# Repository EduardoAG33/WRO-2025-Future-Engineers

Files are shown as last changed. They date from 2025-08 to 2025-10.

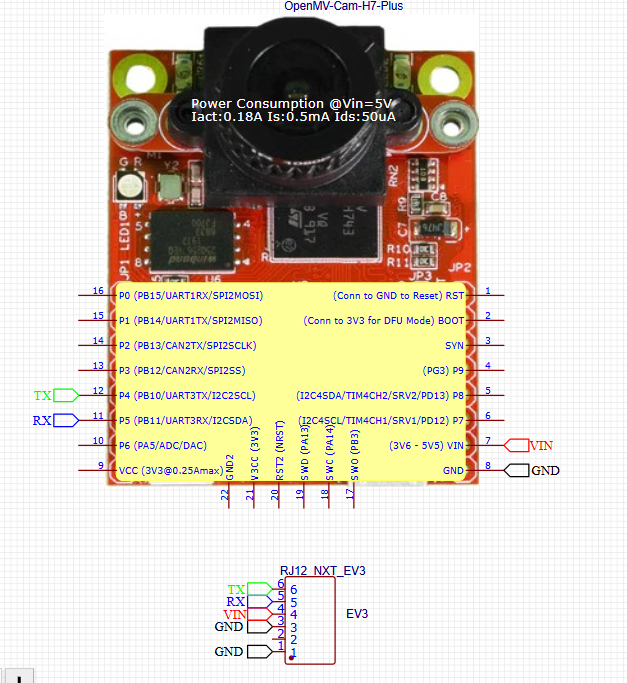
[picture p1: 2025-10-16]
Schemes/open mv schematic.png

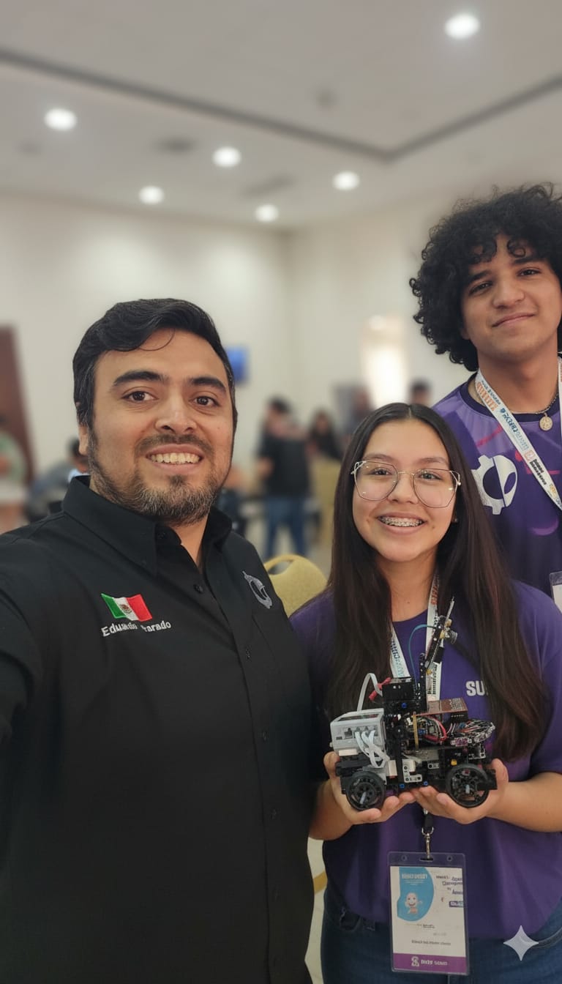
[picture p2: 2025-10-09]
Team-Photos/Team photo.jpeg

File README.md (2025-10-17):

# 🤖 WRO-2025-Future-Engineers

Official repository of Team Los Grises Superiores for the **Future Engineers – World Robot Olympiad 2025**.  
<div align="center">
team-image
</div>

---

## 📸 Team photo
<div align="center">
  team-photo
</div>

---

## 👥 Team Members

### Eduardo Alvarado Gonzalez
<div align="center">
Eduardo Gonzalez
</div>

**Role:** Coach and founder

An engineer and professor founded the **Los Grises Superiores** in 2014, since then with outstanding national and international participations.

---

### Eric Daniel Guerrero Uresti
**Age:** 22
<div align="center">
  Eric Guerrero photo
</div>

**Role:** Programming & Mechanics

I started participating in robotics tournaments from 2016 to 2019, achieving **two second places** in the Mexican Robotics Tournament (TMR). Due to the **Covid-19 pandemic**, I couldn’t compete again until 2024, when I returned as a **coach** in TMR and WRO, earning a spot at the international competition. I am currently in my final year of **Mechatronics Engineering**.

---

### Paulina Ibarra Martínez
**Age:** 20
<div align="center">
  Paulina Martinez photo
</div>

**Role:** Programming & Electronics

I have been part of the **Robotics Club** at *Escuela Normal Superior “Profr. Moisés Sáenz Garza”* for three years, participating in **two Mexican Robotics Tournaments**, achieving **5th place** in the most recent one. Starting in 2024, I became a **junior coach**, achieving **third place** in WRO 2024 and **first place nationally** in the Mexican Robotics Tournament 2025.

---

## 📚 Contents
- [Project Overview](#project-overview)
- [Vehicle Photos](#vehicle-photos)
- [Components and Hardware](#components-and-hardware)
- [Mobility Management](#mobility-management)
  - [Chassis](#chassis)
  - [Steering System](#steering-system)
  - [Movement and Traction System](#movement-and-traction-system)
  - [Differential](#about-differential)
- [Power and Sense Management](#power-and-sense-management)
  - [Power Management](#power-management)
  - [Sense Management](#sense-management)
- [Obstacle Management](#obstacle-management)
  - [Vision System](#vision-system)
- [Calibration](#calibration)
- [Detection and Avoidance Strategies](#detection-and-avoidance-strategies)
- [WRO 2025 Competition Info](#wro-2025-competition-info)

---

## Project Overview

### Abstract

We present the **development and implementation of an autonomous vehicle** designed for the **World Robot Olympiad 2025 – Future Engineers** category.  
The competition challenges participants to design, construct, and program a self-driving car capable of completing specific tasks under variable environmental and rule-based conditions.

The **Future Engineers** category consists of **two main challenges**:

1. **Open Challenge**  
   - The vehicle must autonomously complete **three laps** on a predefined track.  
   - The **starting position** and **driving direction** (clockwise or counterclockwise) are **randomly assigned** before each run.

2. **Obstacle Challenge**  
   - Similar to the Open Challenge, but the vehicle must **detect and react to colored pillars** acting as traffic signals:  
     - **Red pillars → Turn right**  
     - **Green pillars → Turn left**

**Documentation:**  
Documentation is a critical component of the challenge, as it reflects the team’s **engineering process**. Teams are required to maintain a **public repository** including code, CAD files, logs, and other technical documentation.

For full rules and official specifications:  
🔗 [WRO 2025 Future Engineers – General Rules (PDF)](https://wro-association.org/wp-content/uploads/WRO-2025-Future-Engineers-Self-Driving-Cars-General-Rules.pdf)

---

## Vehicle Photos

<div align="center">

| Front | Back |
|:--:|:--:|
 |  |

| Bottom | Top |
|:--:|:--:|
| Top | Bottom |

| Left | Right |
|:--:|:--:|
| Left | Right |

</div>

---

## 🎥 Project Videos

<div align="center">

### 🧩 Open Challenge  


---

### 🚧 Obstacle Challenge  


</div>

---

---
## Components and Hardware

| Component | Description | Image | Purchase Link |
|---|---|---|---|
| **45544 LEGO MINDSTORMS Education EV3 Core Set** | Forms the foundational structure and chassis. | <div align="center">EV3 Core Set</div> | [Buy here](https://bricks-store.com/esp/item/585/66/45544-set-base-lego-mindstorms-education-ev3) |
| **OpenMV Cam H7 Plus** | Smart camera for navigation and obstacle detection. | <div align="center">OpenMV Cam H7 Plus</div> | [Buy here](https://openmv.io/products/openmv-cam-h7-plus) |
| **HC-SR04 Ultrasonic Sensor** | Distance measurement sensor. | <div align="center">HC-SR04</div> | [Buy here](https://uelectronics.com/producto/sensor-ultrasonico-hc-sr04/) |
| **DFRobot URM09 Ultrasonic Sensor (Gravity Analog)** | This ultrasonic sensor features an open dual-probe design and uses the standard Gravity PH2.0-3P vertical connector. Compatible with controllers operating at 3.3V or 5V logic levels. | <div align="center">DFRobot Ultrasonic Sensor</div> | [Buy here](https://wiki.dfrobot.com/URM09_Ultrasonic_Sensor_(Gravity_Analog)_SKU_SEN0307) |
| **Arduino Nano** | ATmega328-based microcontroller for control tasks. | <div align="center">Arduino Nano</div> | [Buy here](https://www.steren.com.mx/placa-de-desarrollo-nano.html) |
| **4x4 RGB LED Matrix** | Compact display module consisting of 16 individual LEDs arranged in a 4-row by 4-column grid. | <div align="center">4x4 RGB Matrix</div> | [Buy here](https://mvelectronica.com/producto/matriz-de-led-rgb-4x4-ws2812-16bits-a-5v-led-5050) |
| **Mini 560 Step-Down Regulator** | Converts a higher voltage power source to a lower voltage efficiently. | <div align="center">Mini 560</div> | [Buy here](https://uelectronics.com/producto/mini-560-regulador-step-down/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) |
| **DFRobot Gravity BNO055** | Intelligent 9-axis Absolute Orientation Sensor integrating a triaxial accelerometer, gyroscope, geomagnetic sensor, and a 32-bit microcontroller. | <div align="center">BNO055</div> | [Buy here](https://es.aliexpress.com/i/32950220044.html?gatewayAdapt=glo2esp) |
| **Digital Voltmeter** | Measures the electrical potential difference between two points in a circuit. Ideal for monitoring battery voltage and ensuring stable power supply. | <div align="center">Voltmeter</div> | [Buy here](https://www.amazon.com.mx/Volt%C3%ADmetro-pulgadas-volt%C3%ADmetro-protecci%C3%B3n-amarillo/dp/B07P1RV5B1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) |
## Mobility Management

### Chassis
The main chassis consists of LEGO pieces selected for their accessibility and for enabling a compact and efficient design. Initially, the prototype was designed using Studio 2.0 software to ensure proper part selection and structural balance.  
For the second level, an acrylic base (acrylate polymer) was used to support the ultrasonic sensors. The shape of this base was customized as part of the design by applying heat to specific areas to mold it into the desired form.  
This level integrates five ultrasonic sensors, strategically distributed to enhance environmental detection and obstacle avoidance.  
This design was made in OnShape:

<div align="center">
Ultrasonic and PCB Base
</div>

The elaboration process:

Using a heat gun, each side of the acrylic base designated for the sensors was carefully heated. Once the material reached the appropriate temperature, it was bent using a mold to achieve the 90° angle required for the optimal positioning and field of view of the sensors.

<div align="center">
Acrylic bending     
Molded base
</div>

The final result is mounted on the robot:

<div align="center">
Mounted base
</div>

This base is attached to the chassis using four screws in the middle to give it stability, and on top of this locate the PCB is located where the ultrasonic sensors are connected.

The measurements for the sensor support can be found in the datasheet.

<div align="center">
sensor support
</div>

## DATASHEET:

https://github.com/EduardoAG33/WRO-2025-Future-Engineers/blob/main/Others/HC-SR04_Datasheet_with_Dimensions%20(1).pdf

**base 3**

On the PCB board, we mounted an additional acrylic base to secure the camera, and to place a voltmeter and a switch for the 18650 batteries. The gyroscope sensor is located in the central part of the assembly for optimal orientation measurement.

<div align="center">
PCB acrylic base
</div>

**view in the vehicle**

<div align="center">
view in the vehicle
</div>

And for the upper level of the robot, we have the support for the camera and the Neo pixel light:  

<div align="center">
camera support
</div>

The support is positioned at a 70° inclination to ensure the vehicle remains within the maximum allowed height. This angle was carefully chosen to optimize the camera’s field of view, as detailed in the Power and Sense Management section.

**Changes and improvements**

Initially, the robot used two cameras. The first camera detected walls, while the second read floor lines for lap counting and identified pillar colors in the Obstacle Challenge. This setup aimed to avoid extra sensors due to the cameras’ high precision.

However, issues arose with ambient light sensitivity, calibration time, and battery consumption. To improve reliability, the second camera was replaced with five ultrasonic sensors positioned at frontal, 90°, and 45° angles to measure distances to walls.

The sensors communicate with the EV3 via two Arduino Nanos: one collects the data, and the other sends it via I2C. The system is mounted on a custom PCB.

**Before:**



**Now**



## Base for the VL53L0X

**Solidworks software design**(metric system in mm)

<div align="center">
VL53 base design
</div>

**draw measurements**

<div align="center">
draw measurements
</div>

This custom piece is designed to fit perfectly with LEGO components, allowing it to be mounted on the chassis and securely hold the sensor according to the dimensions specified in its datasheet.

The custom piece and sensor are precisely positioned to ensure optimal alignment and secure integration with the LEGO chassis, based on the sensor’s datasheet dimensions.

<div align="center">
custom piece
</div>

## Problems and solutions
**Change of the sensor** 

we decided to change the previous sensor (VL53L0X) since when doing tests we had performance failures based on the walls since the distances varied a lot because the sensor laser is affected by the black color of the walls. We determined this by changing to a white color and seeing that the distances no longer varied with this, at the time of having the error this causing it to collide with the stops.
Solution:
The change was implemented for an ultrasonic DF robot URM09, it is working better, the objective changed it was no longer necessary to use it for parking, but as an aid to the turn sensor at the end of the laps of the open challenge round in case the vehicle finished outside the section, this ultrasonic would mark the distance (or the one in front depending on the height at which the robot finishes) to join the final arrival area.
To place the sensor, it only fits on the base of the previous one.
<div align="center">


---

**Chassis render**
<div align="center">
chassis render
</div>

**Assembly manual:**
[chassis assambly instruction.pdf](https://github.com/user-attachments/files/22890187/chassis.assambly.instruction.pdf)

**material that makes up the structure of the chassis:**
<div align="center">
material 1
</div>

<div align="center">
material 2
</div>

<div align="center">
material 3
</div>

In the Mexican National Tournament, we only used one differential, and the robot dimensions were both wider and taller. For the updated version, we decided to implement two differentials, as this configuration provides significantly better control when moving forward. Additionally, reducing the robot’s overall dimensions helps prevent collisions with obstacles and makes it easier to maneuver around them.

---

### Steering System
The EV3’s middle motor converts rotational motion into steering movement through a gear train mechanism. The wheels are linked by a connecting rod, allowing them to move freely. With the assistance of the front differential, this setup transmits motion through the drivetrain to the rear motors, enabling smooth and controlled movement.

The steering rotation is limited to 45 degrees due to the chassis design; however, this range is sufficient for proper turning and obstacle avoidance. If needed, the rotation angle can be further reduced through the block programming.  
**Functionality:**

- **Pinion (engranaje circular):** The circular gear located at the center of the structure. When it rotates, it moves the rack from side to side.  
- **Rack (toothed bar):** A long bar with teeth that meshes with the pinion. When the pinion turns, the rack slides horizontally.  
- **Wheel connection:** The ends of the rack are linked to the wheels through steering arms. When the rack moves, it pushes or pulls these arms, causing the wheels to turn.

<div align="center">
  steering system
  <p><em>Steering system render</em></p>
</div>

**material that makes up the structure of the steering:**
<div align="center">
 steering material
</div>
  
**Assembly manual**
[Sterring system manual.pdf](https://github.com/user-attachments/files/22892572/Sterring.system.manual.pdf)

---

### Movement and Traction System
Two medium motors with differential system transmit energy to wheels. Transmission: 20-tooth → 12-tooth gears → 28-tooth → 20-tooth driving wheels. Position accuracy ±1°, torque 0.08 Nm, speed 240 RPM.  
According to the competition rules, the engines cannot be mounted directly on the wheels. Therefore, we chose to implement a transmission system connected to the differential, allowing the engine’s motion to be transferred to the tires, causing them to rotate.  
We decided to use two motors because they offer greater speed, power, and stability to the vehicle’s base compared to using only one. This configuration allows for a more balanced distribution of torque, improving traction and control during movement. After testing different options, we chose the medium LEGO motor because it provides an optimal balance between size, weight, and energy efficiency, making it ideal for our chassis design. Additionally, its compact structure facilitates integration into the transmission system while maintaining low power consumption and reliable performance.

<div align="center">
traction system
</div>

**Traction system render**

<div align="center">
 traction render
</div>

**Traction system manual**
[traction system manual.pdf](https://github.com/user-attachments/files/22892680/traction.system.manual.pdf)

---

### About Differential
Distributes torque to wheels, enabling smooth cornering. Input via pinion and crown gears. Outer wheel rotates faster in turns, inner wheel slower, straight motion equal.

A differential is a mechanical component that allows wheels on the same axle to rotate at different speeds while transmitting power from the motor. This is especially important when a vehicle turns, as the outer wheel needs to travel a greater distance than the inner wheel. The differential distributes torque between the wheels, ensuring smooth and efficient movement, reducing tire wear, and improving traction and stability. In our design, the differential receives motion from the transmission and transfers it to the tires, enabling precise control of the vehicle’s movement.

<div align="center">
  Differential example
  <p><em>Image: Differential example</em></p>
</div>

**LEGO Differential Calculations – Gear Ratio Table**

| Gear Ratio (i) | Wheel Speed (m/s) | Wheel Torque (N·m) | Traction Force (N) |
|---|---|---|---|
| 1:1 | 0.50 | 0.20 | 7.14 |
| 2:1 | 0.25 | 0.40 | 14.3 |
| 3:1 | 0.17 | 0.60 | 21.4 |
| 4:1 | 0.13 | 0.80 | 28.6 |
| 5:1 | 0.10 | 1.00 | 35.7 |

- Assumes **motor speed = 170 rpm**, **torque = 0.2 N·m**, **wheel radius = 0.028 m**.

## Impact of vehicle dimensions

The robot’s compact dimensions — 15 cm wide, 29 cm long, and 26 cm high — allow for the precise integration of both the steering and traction systems, enabling accurate and stable turns.
It was designed to be as narrow as possible, minimizing the risk of collisions with walls during sharp turns.

In the Open Challenge, our robot uses five ultrasonic sensors together with an OpenMV camera, creating an intelligent system that allows it to detect obstacles and move safely.
The front ultrasonic sensor detects when a curve begins. The camera and ultrasonic sensors work together through a PID control system, and we also correct measurement errors from the ultrasonic sensors using gain adjustments depending on their inclination.
This helps the robot identify whether a corridor is open or closed, effectively avoiding collisions with walls and improving navigation accuracy.

For the Obstacle Challenge, we took advantage of the robot’s width, length, and height to optimize its performance in different scenarios.
The width, being narrow, allows the vehicle to pass easily between pillars without collisions.
The length was optimized for the parking task — we extended the vehicle and added a rear spoiler to make the most of the rule that define the parking area as 1.5 times the vehicle’s length. This provides more freedom and precision when parking.
The height was designed to ensure better visibility of obstacles, allowing the sensors and camera to detect objects from their base to their top. This also prevents the robot from re-detecting the same obstacle after an evasive maneuver or a sharp turn, ensuring smoother navigation and preventing unnecessary repeated avoidance actions.

---

## Power and Sense Management
The Power and Sensor Management system of the vehicle is engineered to optimize energy distribution and ensure reliable operation of all electronic components. It carefully regulates the power supply to motors and sensors, maintaining stability and efficiency under varying load conditions. This system enables precise control over sensor readings and motor performance, supporting accurate navigation, obstacle detection, and overall vehicle functionality.
   
### Battery for EV3:
<div align="center">
EV3 Battery
</div>

**Specifications:**

| Specification | Details |
|---|---|
| **Battery Type** | Rechargeable Lithium-Ion (Li-Ion) |
| **Nominal Voltage** | 7.4 V (Li-Ion) |
| **Capacity** | 2000 mAh (Li-Ion) |
| **Typical Usage Time**  | Approximately 1–2 hours with intensive use of motors and sensors |
| **Charging Time** | 1.5 – 2 hours (Li-Ion) |
| **Weight** | 160 g (Li-Ion) |
| **Connector** | Integrated in EV3 Brick |
| **Note** | Using the official rechargeable Li-Ion battery is recommended for optimal performance and to avoid voltage variation from AA batteries |

This battery is the recommended power source for the LEGO EV3. There are two options: the official rechargeable battery or six AA batteries. Using the official battery is preferable, as it provides a stable and consistent voltage, ensuring reliable operation of motors and sensors under varying loads. Additionally, it offers longer runtime, making it ideal for extended use and competitive.

### Battery 18650
<div align="center">
18650 battery
</div>

**Specifications:**

| Specification | Description |
|---|---|
| **Type** | Li-ion Rechargeable |
| **Model** | 18650 |
| **Nominal Voltage** | 3.7 V |
| **Full Charge Voltage** | 4.2 V |
| **Capacity** | 2600–3500 mAh (typical) |
| **Discharge Current** | 5–10 A (continuous), up to 20 A (peak) |
| **Charging Current** | 0.5–1 C |
| **Dimensions** | 18 mm diameter × 65 mm length |
| **Weight** | ~45 g |
| **Cycle Life** | 300–500 cycles (typical) |
| **Protection Circuit**  | Optional (PCB for overcharge/discharge/cutoff)|

The 18650 is Li-ion battery is a high-capacity rechargeable cell widely used in electronics and robotics due to its stable voltage output, high energy density, and long cycle life.
can safely deliver continuous currents of 5–10 A and occasional peak currents up to 20 A,When paired with a protection circuit, it safeguards against overcharging, over-discharging, and short circuits, increasing safety and durability.
In this setup, we use 18650 batteries to power the Arduino Nano for controlling the ultrasonic sensors. Two 18650 cells are connected to a DC-DC step-up module to increase the voltage, which is then supplied to the Arduino, ensuring stable operation and consistent sensor readings, we We use two 18650 batteries connected in series, providing an output voltage of approximately 7V.

### Microcontroller(Arduino nano)
<div align="center">
Arduino Nano large
</div>

**Specifications:**

| Specification | Description |
|---|---|
| **Microcontroller** | ATmega328P |
| **Operating Voltage** | 5 V |
| **Input Voltage (recommended)** | 7–12 V |
| **Input Voltage (limit)** | 6–20 V |
| **Digital I/O Pins** | 14 (6 PWM outputs) |
| **Analog Input Pins** | 8 |
| **DC Current per I/O Pin** | 40 mA |
| **Flash Memory** | 32 KB (2 KB used by bootloader) |
| **SRAM** | 2 KB |
| **EEPROM** | 1 KB |
| **Clock Speed** | 16 MHz |
| **USB Connection** | Mini USB |
| **Dimensions** | 45 mm x 18 mm |
| **Weight** | ~7 g |

The Arduino Nano is a compact,microcontroller board based on the ATmega328P. Despite its small size, it offers full functionality with 14 digital I/O pins, 8 analog inputs, and a 16 MHz clock speed.
It operates at 5V and can be powered through a Mini USB connection, a regulated 5V pin, or an external 7–12V input,

### Medium motor EV3
<div align="center">
EV3 Medium Motor
</div>

**Specifications**

| Specification | Description |
|---|---|
| **Model** | EV3 Medium Motor (45503) |
| **Type** | Servo Motor with integrated rotation sensor |
| **Operating Voltage** | 9 V DC |
| **Nominal Power** | 2.5 W |
| **No-load Speed** | ~260 rpm |
| **Stall Torque** | ~8 N·cm (0.08 N·m) |
| **Stall Current** | ~0.7 A |
| **Tacho Sensor Resolution** | 1° (360 counts per rotation) |
| **Weight** | 75 g |
| **Cable Length** | 25 cm |
| **Connector Type** | EV3 Plug |
| **Control Features** | Speed, position, and direction control |

It operates at 9V DC and is designed to provide a balance between speed and torque, making it suitable for medium-load
We connect these motors directly to the EV3, and control them directly with the programming block for these motors, which in our robot consumes the following:

EV3 Brick controls all motors. Powered by 10V 2050 mAh battery.  
- **Movement motors (2):** 150–250 mA  
- **Steering motor (1):** 120–250 mA
  
In terms of power consumption, the motor typically draws around 250–300 mA under normal load, but this can increase up to 1.2 A when operating under heavy load or stall conditions. Its power output reaches approximately 2.5 W, depending on the applied voltage and load.

**measures and details**

| **Feature** | **Value** |
|---|---|
| **Total length (with axle)** | 7.1 cm |
| **Body length** | 5.5 cm |
| **Width** | 3.8 cm |
| **Height** | 4.7 cm |
| **Axle diameter (LEGO cross axle)** | 4.8 mm |
| **Weight** | ≈ 75 g |
| **Connector type** | EV3 RJ12 (6-pin) |
| **Rotation sensor resolution** | 1° per step |
| **Rotation direction** | Bidirectional |
| **Position feedback** | Integrated rotation sensor |

<div align="center">
  Medium Motor Voltage
  <p><em>Image: Medium Motor Voltage</em></p>
</div>

We found the information about the motor here:
[Hardware Developer Kit PDF](https://github.com/user-attachments/files/22328277/hardware_developer_kit.pdf)

## OpenMv H7 plus
<div align="center">
OpenMV H7
</div

**PCB Design**
<div align="center">

</div

**PCB Schematic**
<div align="center">

</div

## Specifications

| Feature | Details |
|---|---|
| Processor | ARM® Cortex®-M7, 32-bit, 480 MHz with Double Precision FPU |
| RAM | 512 KB SRAM |
| Flash Memory | 2 MB Flash |
| Image Sensor | OV5640 (5 MP) or MT9M114 (1/3") with M12 lens mount |
| Resolution | Up to 2592×1944 (OV5640) or 640×480 (MT9M114) |
| Frame Rate | Up to 80 FPS (MT9M114), 75 FPS (OV5640) |
| Image Formats | Grayscale, RGB565, JPEG, BAYER, YUV422 |
| Connectivity | Full-speed USB (12 Mbps), microSD card socket (up to 64 GB), SPI, I2C, CAN, UART |
| GPIO Pins | 10 I/O pins (3.3V logic, 5V tolerant), supports PWM and interrupts |
| Power Supply | 5V via USB or VIN pin, 3.3V regulated output |
| Onboard LEDs | RGB LED and two high-power 850nm IR LEDs |
| Programming Language | MicroPython via OpenMV IDE |
| Operating Voltage | 5V DC |
| Dimensions | 40 mm × 40 mm × 15 mm |
| Weight | Approximately 25 g |

The OpenMV H7 Pro is a low-power machine vision camera designed for embedded systems. It operates at 5V, drawing a typical current of 250–300 mA during normal operation, and up to 480 mA when all peripherals are active.
Key considerations for energy management:

**IR LEDs:** High current draw when enabled; use sparingly to extend battery life.

**MicroSD Logging:** Writing images or logs increases power usage slightly.

**Processing Load:** More complex algorithms (e.g., object recognition, color tracking) increase CPU activity and power draw.

**GPIO Outputs:** PWM and other peripherals also consume extra current.
  
Powered at 3.3V, max 480 mA, connected via custom PCB to EV3.

The camera is mounted at a 70° angle on the highest point of the vehicle. This position was selected to maximize the field of view, allowing the vehicle to better detect obstacles and monitor the track, covering a larger area and facilitating the identification of the designated parking zone. Initially, the camera was positioned at the front of the vehicle, above the steering system. However, it faced visibility issues, as the field of view was limited, which led to errors when avoiding the pillars. 

Block Camara Ev3



With this block, we can obtain parameters such as the object's center position (X and Y) and also measure its width and height.
The code shown below is an example of a line follower, which uses these parameters to detect and follow a path accurately.

**You can found the block here:** https://github.com/ofdl-robotics-tw

## 4x4 RGB LED Matrix

<div align="center">
4x4 RGB Matrix large
</div>

**Specifications**

| Specification | Details |
|---|---|
| **Dimensions** | 30 x 30 mm |
| **LED Configuration** | 4 x 4 (16 RGB LEDs) |
| **LED Pitch** | 3 mm |
| **Operating Voltage** | 5V DC |
| **Current Consumption** | 60–80 mA per LED at full brightness |
| **Data Interface** | Single-wire digital input (Data In) |
| **Signal Protocol** | WS2812B or compatible |
| **Power Input** | VCC and GND |
| **LED Type** | Integrated RGB LEDs with built-in control |
| **Color Depth** | 16.7 million colors (24-bit) |
| **Control Method** | PWM (Pulse Width Modulation) |
| **Addressability** | Individually addressable LEDs |
| **Cascading Capability** | Yes, via Data Out → Data In |
| **Compatible Platforms** | Arduino, ESP32, Raspberry Pi |
| **Libraries** | Adafruit NeoPixel, FastLED |

The 4x4 RGB LED matrix contains 16 individually addressable LEDs. Each LED operates at 5V DC and can draw approximately 60 mA at full brightness when displaying white (all three colors at maximum).

Typical current per LED: 60 mA (max)

Total current for 16 LEDs at full brightness: 16 × 60 mA = 960 mA

**P = V × I = 5V × 0.96A ≈ 4.8 Watts**

We use Neopixel LED to support the camera, as they help improve the distinction of colors in obstacles and the parking lot. The Neopixels are controlled using the NeoPixel library in Arduino, which then sends data to the EV3. This setup allows the EV3 to adjust the intensity of the Neopixels dynamically, enhancing the robot’s color detection and visual accuracy.

A 4x4 WS2812B matrix usually has 3 main pins:

- VCC (Power)
- GND (Ground)
- DIN (Data In)
- DOUT (Data Out) – optional for chaining

## Mini 560 Regulador Step down 

<div align="center">
Mini 560 module
</div>

**Specifications**

| Specification | Description |
|---|---|
| **Model** | Mini 560 DC-DC Step-Down Converter |
| **Input Voltage (Vin)** | 4.5V – 28V DC |
| **Output Voltage (Vout)** | Adjustable from 0.8V – 20V DC |
| **Default Output (pre-set)** | 5V (depending on module version) |
| **Output Current (Iout)** | Up to 3A (recommended continuous current: 2A for stability) |
| **Efficiency** | Up to 95% (depending on voltage and load) |
| **Switching Frequency** | 1.5 MHz |
| **Voltage Ripple** | < 30 mV (typical) |
| **Load Regulation** | ±0.5% |
| **Conversion Type** | Step-Down (Buck) Converter |
| **Control IC** | MP2307 or similar synchronous rectifier chip |
| **Operating Temperature** | -40°C to +85°C |
| **Dimensions** | 22 mm x 17 mm x 4 mm |
| **Protection Features** | Short-circuit, over-temperature, and over-current protection |
| **Typical Applications** | Power supply for microcontrollers, sensors, cameras, LED strips, and communication modules |

The Mini 560 Step-Down Regulator is used to efficiently convert higher input voltages to lower, stable output voltages suitable for powering microcontrollers, sensors, and other electronic modules in the robot. Its compact design and high efficiency make it ideal for embedded and portable applications.

We use this module to regulate the voltage supplied to the two Arduino PCBs, stepping it down from 7V to 5V to ensure stable operation and optimal performance.

## RM09 Ultrasonic Distance Sensor



## Specifications

| Parameter | Value |
|---|---|
| **Supply Voltage** | 3.3V to 5.5V DC |
| **Operating Current** | 20 mA |
| **Operating Temperature** | -10°C to +70°C |
| **Measurement Range** | 2 cm to 500 cm |
| **Resolution** | 1 cm |
| **Accuracy** | ±1% |
| **Acoustic Frequency** | 40 ± 2 kHz |
| **Ranging Frequency** | Up to 25 Hz |
| **Dimensions** | 47 mm × 22 mm (1.85" × 0.87") |
| **Output Type** | Analog voltage output |
| **Beam Angle** | ±15° |
| **Distance Formula** | `Distance = Vout (mV) × 520 / Vin (mV)` |

## Description

The RM09 Ultrasonic Distance Sensor (Gravity URM09) is a high-precision sensor designed for distance measurement applications. It operates by emitting ultrasonic waves and measuring the time it takes for the echo to return, providing accurate distance readings from 2 cm up to 500 cm. With a resolution of 1 cm and an accuracy of ±1%, it is suitable for robotics, automation, and obstacle detection projects.  

The sensor features analog voltage output, built-in temperature compensation, and fast ranging up to 25 measurements per second. Its compact design and wide voltage compatibility (3.3V to 5.5V).

We use this sensor to assist with turns. At the end of the three-turn sequence, the robot may exit the section. To address this, the sensor is implemented to measure the distance to the wall and guide the robot forward, ensuring accurate entry into the next section.

---

## DF Robot Gravity BNO055

<div align="center">
BNO055 module
</div>

| Specification | Description |
|---|---|
| **Model** | DFRobot Gravity BNO055 |
| **Sensor Type** | 9-Axis Absolute Orientation Sensor |
| **Integrated Sensors** | 3-axis accelerometer, 3-axis gyroscope, 3-axis magnetometer |
| **Operating Voltage (Vcc)** | 3.3V – 5V DC |
| **Communication Interface** | I²C (default) or UART |
| **I²C Address** | 0x28 (default) / 0x29 (configurable) |
| **Measurement Range (Accelerometer)** | ±2g / ±4g / ±8g / ±16g |
| **Measurement Range (Gyroscope)** | ±125°/s / ±250°/s / ±500°/s / ±1000°/s / ±2000°/s |
| **Magnetometer Range** | ±1300 µT (X, Y), ±2500 µT (Z) |
| **Absolute Orientation Output** | Quaternion, Euler angles, linear acceleration, gravity vector |
| **Output Data Format** | 16-bit data through I²C or UART |
| **Operating Temperature** | -40°C to +85°C |
| **Power Consumption** | ~12 mA (typical) |
| **Dimensions** | 30 mm × 22 mm × 7 mm |
| **Mounting Type** | Gravity compatible (3-pin interface) |
| **Applications** | Robotics, motion tracking, navigation, stabilization, and orientation detection |

---

### Description

The **DFRobot Gravity BNO055** is an intelligent 9-axis absolute orientation sensor that combines an accelerometer, gyroscope, and magnetometer with an onboard 32-bit microcontroller running Bosch sensor fusion algorithms.  
This integration allows the module to directly output orientation data (Euler angles or quaternions) without requiring complex calculations from the main microcontroller.

In our robot, this sensor is used to determine the **precise orientation and tilt** of the vehicle, improving stability and movement control during navigation tasks.

---

### Pinout and Function

| Pin | Name | Description |
|---|---|---|
| **VCC** | Power Input | Connect to 3.3V–5V DC power supply |
| **GND** | Ground | Common ground with the microcontroller |
| **SDA** | I²C Data | Data line for I²C communication |
| **SCL** | I²C Clock | Clock line for I²C communication |
| **RX / TX** | UART Communication | Optional serial communication interface |
| **RST** | Reset | Used to reset the sensor (optional) |

We use this sensor to count laps on the track, processing the data with the Arduino to send the information to the Ev3 and then with a programming block we decide the count of the laps based on its initial position where it will also end in the same place

## Ultrasonic HC-SR04

<div align="center">

</div>

### Specifications

| **Parameter** | **Description** |
|---|---|
| **Operating Voltage** | 5V DC |
| **Operating Current** | 15 mA (typical) |
| **Frequency** | 40 kHz |
| **Max Range** | 400 cm (4 m) |
| **Min Range** | 2 cm |
| **Accuracy** | ±3 mm |
| **Measuring Angle** | < 15° |
| **Trigger Input Signal** | 10 µs TTL pulse |
| **Echo Output Signal** | TTL signal, proportional to distance |
| **Dimensions** | 45 mm x 20 mm x 15 mm |
| **Working Temperature** | -15°C to +70°C |

The **HC-SR04** is an ultrasonic distance sensor that uses sonar to determine the distance to an object.  
It provides accurate and stable readings and is commonly used in robotics for obstacle detection and distance measurement.

### Pin Connections

| **Pin** | **Label** | **Description** |
|---|---|---|
| 1 | VCC | Power supply (+5V) |
| 2 | Trig | Trigger input to start measurement |
| 3 | Echo | Output pulse proportional to distance |
| 4 | GND | Ground connection (0V) |

**Program in Ev3 to solve the Open challenge using an ultrasonic sensor and gyro**

<div align="center">

  
First, the front ultrasonic sensor measures a specific distance to determine when to start a curve.
During the turns, we correct potential errors from the ultrasonic sensors positioned at 45° and 90°, ensuring more accurate distance readings and smoother movement.

A PID control system is then used to manage both the speed and steering angle, allowing the robot to perform stable and precise turns.

After completing the curve, the same process is repeated to identify whether the corridor is open or closed, since each type requires different movement configurations and adjustments.

**PCB**
During the PCB design process, we engraved the circuit using a laser machine. Afterward, we applied ferric chloride to etch away the excess copper, leaving only the designed traces. The board was then drilled, cleaned, and prepared for soldering and component assembly.

The PCBs designed for the ultrasonic sensors and camera are fully fabricated, cleaned, and ready for component mounting and final assembly.



**arduino's for the ultrasonic sensors design**



**ultrasonic connections**



This PCB is powered by two 18650 lithium batteries connected in series, providing a total supply voltage of approximately 8V. A voltage regulator steps down the voltage to 5V to reliably power the ultrasonic sensors and the NeoPixel LED module.

The system architecture includes two Arduino microcontrollers:

Arduino 1 handles the acquisition and processing of data from the ultrasonic sensors.

Arduino 2 manages data communication and transmits processed information to the LEGO EV3 brick via the I2C communication protocol.

This configuration enables seamless integration with the EV3 environment, allowing real-time data exchange and programming through EV3 graphical blocks.

**Arduino Code ultrasonic program**

 
 

## explication

### Libraries
- **`Wire.h`**: Handles I2C communication with the BNO055 sensor.  
- **`SoftwareSerial.h`**: Provides an extra serial port for communication with a master device.  
- **`NewPing.h`**: Efficient library for reading HC-SR04 ultrasonic sensors with filtering and timing control.  

### Ultrasonic Sensors
- Four `NewPing` objects are created for the sensors: `l90`, `l45`, `r45`, `r90`.  
- Maximum measurement distance is **200 cm**.  

### Lap Detection
- **`LAPS_METHOD = 3`**: Combines accumulated yaw and gate crossing for reliable lap counting.  
- **`LAP_TICKS16`**: 360° × 16 ticks per full rotation.  
- **`LAP_MIN_MS`**: Minimum time (ms) between lap counts to prevent false detections.  
- **`GATE_HALF_WIDTH`** + **`GATE_HYST`**: Gate angle thresholds for lap detection.  

### UART Communication
- Uses `SoftwareSerial` on **D2 (RX) / D3 (TX)** to send CSV-formatted sensor data to a master device.  

### BNO055 Sensor
- Custom minimal I2C implementation without external libraries.  
- Provides **yaw angle (heading)** in 16 ticks.  
- Initializes in **NDOF mode** and ensures valid heading data before operation.  

### Angle Utilities
- **`yawDelta16()`**: Calculates the difference between two yaw readings, accounting for ±360° wraparound.  
- **`angDiffDeg()`**: Calculates angular difference normalized to -180° … 180°.  

### State Variables
- Store previous yaw (`yaw_prev16`), accumulated yaw (`yaw_accum16`), lap count (`lap_count`), gate state, and BNO055 initialization status (`bno_ok`).  

### Lap Calculation Functions
- **`timeOk()`**: Ensures laps are not counted too quickly.  
- **`tryCountLapAccumYaw()`**: Counts laps based on accumulated yaw rotation.  
- **`tryCountLapGate()`**: Counts laps when crossing a gate angle threshold.  
- **`resolveLapMethod3()`**: Combines both methods for a reliable lap count.  

### Ultrasonic Filter
- **`filteredPing()`**: Applies a median + average filter on multiple readings to remove outliers and improve measurement stability.  

### Setup
- Initializes **Serial**, **SoftwareSerial**, and **I2C** communication.  
- Initializes **BNO055 sensor**.  
- Sends CSV header:  

## 🧠 Arduino Nano – Ultrasonic + IMU Sensor Fusion System

### Overview
This program is designed for an **Arduino Nano (ATmega328P)** that integrates **four HC-SR04 ultrasonic sensors** and a **BNO055 IMU**.  
The system measures distances, detects orientation, and counts laps, transmitting the processed data in **CSV format** via **UART** to a LEGO EV3 or another master controller.

---

### ⚙️ Features
- **Four ultrasonic sensors** (left/right at 45° and 90°) for wall and obstacle detection.  
- **BNO055 IMU** (communicated via I2C, no Adafruit libraries) for orientation tracking.  
- **Lap counting system** based on full rotations and angular gate detection.  
- **Median + range filter** for noise reduction in ultrasonic readings.  
- **UART serial communication** at 115200 baud, sending real-time data in CSV format:

**2 Arduino code for communication**

 

## Arduino Slave with NeoPixel & HC-SR04 Sensors – I2C Communication

This code runs on an Arduino acting as an **I2C slave** that collects sensor data, maps it, and sends it to a master device. It also controls a NeoPixel matrix for lighting feedback.

### Libraries
- **`Wire.h`**: Handles I2C communication as a slave device.  
- **`SoftwareSerial.h`**: Creates a secondary serial port to read CSV data from another Nano.  
- **`Adafruit_NeoPixel.h`**: Controls a 16-LED NeoPixel matrix.  
- **`NewPing.h`**: Manages ultrasonic HC-SR04 sensors efficiently.

### Sensors
- Front ultrasonic sensor (`frontU`) reads distance in cm.  
- Rear analog sensors connected to `A6` and `A7` are scaled to 0–500 units.  
- Additional distance sensors (`l45`, `r45`, `l90`, `r90`) and lap counter are read via a secondary Nano through SoftwareSerial.  

### Data Mapping
- Distance readings are mapped to **-100…100**.  
- Analog readings are mapped to **-127…127**.  
- `frontbyte`, `l45byte`, `r45byte`, `l90byte`, `r90byte`, `A6byte`, `A7byte` store the mapped values.

### NeoPixel Control
- Initializes a 16-LED matrix on pin 9.  
- Brightness is mapped using `POT_LUZ` from 0–100 to 0–255.  
- Shows initial static color on setup.

### I2C Communication
- Arduino acts as **slave with address 0x04**.  
- `sendData()` sends a requested byte depending on `mind_n_DATO_1`.  
- `onreceiveEvent()` reads commands from the master device.  
- Case 6 uses a **flag (`linkSent`)** to send a single pulse only once.  

### CSV Processing
- Receives lines from the secondary Nano via `SoftwareSerial`.  
- Each CSV line contains 5 values: `l90, l45, r45, r90, laps`.  
- `processLine()` parses the string and updates sensor variables.

### Loop Behavior
1. Reads front ultrasonic sensor and analog values.  
2. Reads CSV from the secondary Nano and parses it.  
3. Maps all sensor values to the specified ranges.  
4. Updates internal state for I2C requests.  

---

This setup allows **real-time sensor fusion**, mapping, and I2C data delivery to a master controller while providing visual feedback through the NeoPixel matrix.

**I2c Communication block to EV3**

<div align="center">


**Reference for connect the ev3 to Arduino**

https://www.dexterindustries.com/howto/connecting-ev3-arduino/

We use ultrasonic sensors connected via I²C to measure distances, and the robot turns using EV3 blocks.

<div align="center">


---

## Obstacle management

The obstacle avoidance system was designed in accordance with the competition rules: a **red pillar** indicates a right turn, while a **green pillar** indicates a left turn.  
To determine the correct avoidance side, the robot calculates the difference between the **detected X position** from the camera and a predefined **X target**.  
This approach ensures a reliable and consistent maneuver direction, improving the robot’s decision-making during navigation.
he vision system was also designed to support the obstacle avoidance logic.
For this purpose, the X-coordinate at the base of the detected blob was used as the main metric, providing more reliable results than using the object’s area, which occasionally produced inconsistent data.

**Camera calibration**
Fixed camera parameters (auto-gain, auto-white balance, exposure). LAB thresholds adjusted for white, red, green, blue, orange.

**Steps:**
The OpenMV IDE uses MicroPython for programming, and the scripts are directly uploaded to the camera module.
To calibrate the color detection thresholds, follow these steps:

Go to the Tools menu in the top taskbar.

Navigate to Machine Vision → Threshold Editor.

Capture an image from the camera to begin threshold calibration, which allows you to adjust color ranges for precise object or line detection.

**Open Mv CODE**(this code works with the open challenga and obstacle)
---

## Color Calibration (LAB)

For optimal performance, each color threshold must be calibrated under the same lighting conditions as in the competition area.  
Calibration is done using the **OpenMV IDE** → *Tools → Machine Vision → Threshold Editor*.

### Recommended Steps

1. Place the OpenMV camera at the same height and angle used on the robot.  
2. Open the **Threshold Editor** and capture each color region individually.  
3. Adjust the LAB values until detection boxes remain stable and consistent.  
4. Test again under different lighting intensities to ensure robustness.

---

### Example LAB Thresholds

| Color | LAB Min (L, A, B) | LAB Max (L, A, B) | Description |
|---|---|---|---|
| **Red** | (30, 60, 10) | (80, 128, 80) | Vertical red pillar detection |
| **Green**  | (20, -80, 0) | (80, -20, 80) | Vertical green pillar detection |
| **Blue** | (0, 0, -128) | (40, 64, -20) | Floor area detection (blue regions) |
| **White**  | (70, -10, -10) | (100, 10, 10) | Base floor color |
| **Orange** | (35, 40, 60) | (85, 90, 128) | Marked zone or boundaries |
| **Magenta**| (25, 20, -10) | (70, 90, 30) | Reference marker detection |

---

### Tips for Fine Tuning

- Recalibrate colors if lighting changes significantly.  
- Avoid shadows or reflections during calibration.  
- Increase the **ROI area** temporarily to ensure color stability.  
- If detection flickers, apply **EMA filtering** to the color signal.  
- Always validate using both **Pillar** and **Floor** detection modes before final testing.
## Troubleshooting

Below are common issues encountered during setup and calibration, along with their possible causes and solutions.

| Problem | Possible Cause | Solution |
|---|---|---|
| **Pillars are not detected** | Color thresholds too narrow or poor lighting | Recalibrate LAB ranges for red and green; verify ROI zones are correctly positioned. |
| **False positives in floor detection** | Shadows or reflections affecting color reading | Reduce ROI area or add light shielding; adjust white/blue thresholds. |
| **Magenta marker not recognized** | Insufficient color contrast or incorrect ROI height | Increase magenta LAB range; ensure marker is within detection area. |
| **Unstable floor error (err_ema fluctuating)** | Too much noise or rapid color variation | Increase EMA smoothing factor; use median filtering if available. |
| **Data not received by EV3** | LPF2 communication issue | Check wiring between OpenMV (P4, P5) and EV3; confirm baud rate and I²C configuration. |
| **Lag in visualization (slow HUD refresh)** | Debug display consuming resources | Disable HUD by setting `SHOW_DEBUG = False` for smoother performance. |
| **Inconsistent detection in bright areas** | Overexposure in the camera sensor | Lower camera gain or exposure settings in OpenMV IDE. |

**threshold calibration part in the code**

<div align="center">


**In this part of the code we activate the colors (True or False)**

**example the values calibration for the color**

# TH_COLOR = (Lmin, Lmax, Amin, Amax, Bmin, Bmax)  -> always the data is of the major to minor

<div align="center">


---
## Detection and Avoidance Strategies
To improve the system’s response, a dynamic horizontal ROI (Region of Interest) scheme was implemented.
This approach allows the detection of the line’s relative position at different heights of the image, enhancing tracking accuracy.

The position error is converted into a proportional signal within the EV3 controller, where the initial Kp value was set to 1 and later fine-tuned to improve sensitivity in both curves and straight segments.
##  Problems and Solutions

| **Identified Problem** | **Implemented Solution** |
|---|---|
| Light variations on the track caused unstable detections. | The OpenMV camera’s auto-gain, auto-white balance, and exposure parameters were fixed to ensure detection stability. |
| In curves, the robot lost sight of distant pillars. | A compensation strategy was introduced using the base position of the blob, and dynamic ROIs were expanded to maintain coverage. |
| The robot detected very large colored blobs, leading to confusing data. | The X-coordinate at the base of the blob was adopted as the main metric, keeping the area only as a secondary reference. |
| OpenMV scripts were redundant and complicated integration with the EV3. | Data transmissions were unified through LPF2 slots, removing redundancies such as `PRINT_EVERY` and `SEND_EVERY`. |
| The line follower was not reactive to corridor width changes. | The corridor width was incorporated as a proportional correction variable (KP adjustment on the EV3). |
| Risk of collision when the robot failed to recognize pillars correctly. | The pillar ROI was replaced by a black ROI responsible for alerting possible collisions along the path. |

### Line Tracking
Dynamic ROIs provide position error → proportional KP in EV3.

### Corridor Width Regulation
Proportional correction from lower ROIs.

### Obstacle Avoidance
Red → right, Green → left based on X coordinate vs target.

### Data Communication (OpenMV → EV3)
LPF2 protocol: unified data slots.

## Metrics

| **Sensor / Source** | **Extracted Metric** | **Use in Control System** |
|---|---|---|
| **OpenMV – Middle ROI** | Corridor width and intermediate colors (red, green, orange) | Proportional regulation and obstacle anticipation. |
| **OpenMV – Upper ROI** | Position of distant obstacles | Curve support and early avoidance preparation. |
| **OpenMV – Black ROI** | Detection of dark areas (collision) | Collision alert, sending a binary indicator to the EV3. |
| **OpenMV – Color Blobs** | X-coordinate at the base (Y) of the detected object | Determination of the avoidance side (red = right, green = left). |
| **EV3 – Motor Encoders** | Speed and distance traveled | Smooth motion control and maneuver execution. |
| **EV3 – Internal Logic** | Proportional variable (KP) | Dynamic correction for both curves and straight paths. |

**EV3 BLOCKS CODE EXPLICATION**

This is the start of the program. After leaving the parking area, the camera uses comparators to detect the pillar color. It distinguishes between red and green based on the predefined values 3 and 5.

<div align="center">




## Parking Exit and Entrance Area
**Exit**
"For the obstacle challenge, we integrated parts of the open challenge program. In this program, we primarily work with the extended open corridors and track the number of laps using the gyroscope sensor upon completing the general loop. Additional camera modules assist in the detection process.

For pillar detection, we use mapping techniques to identify the precise area of each pillar. Once obstacles are detected, the robot employs a PID control system to execute smooth and precise avoidance maneuvers.

This approach allows the robot to navigate complex environments effectively, combining sensor data, mapping, and control algorithms to safely avoid obstacles while maintaining its course
For exiting the parking space, the robot uses a similar mechanized approach, relying on precise motor rotations and steering adjustments to maneuver safely. The camera continues to play a critical role by detecting the magenta color of the parking area, ensuring that the robot avoids collisions while leaving the space.

Once the exit maneuver is completed, the robot begins the detection of pillar colors using logical comparators. This enables it to distinguish between different pillar colors and make informed navigation decisions for the next stage of its path.

<div align="center">
 
  


**Entrance**

For the parking maneuver, once the robot completes the three laps, it uses a camera-based follower to locate the parking area by detecting the magenta color.
After identifying the parking zone, the robot aligns itself accordingly. Using precise movements, the robot executes a series of maneuvers to position itself parallel within the designated parking space.
This method ensures accurate and autonomous parking, leveraging visual guidance and controlled mechanical adjustments to achieve a reliable placement every time."

<div align="center">


**Recovery in case of crash or stuck**

<div align="center">


The vehicle is designed to prevent getting stuck in the event of a collision. In our programming, if the robot comes very close to a wall, the OpenMV camera detects it as an obstacle. When this happens, the robot executes a reverse maneuver to avoid the collision.

In the event that the robot fails to follow this instruction and collides, potentially becoming stuck, it is programmed to repeatedly attempt the reverse maneuver. This process continues until the robot successfully clears the obstacle and can move forward freely.

This approach ensures that the robot can autonomously recover from unexpected collisions, maintaining continuous operation without human intervention.

## Extra and important information

A **PID controller** is a feedback control system widely used in robotics and automation to maintain a desired state. It continuously calculates the difference (error) between a target value (setpoint) and the current measured value (process variable) and adjusts outputs to minimize this error.  

- **Proportional (P):** Reacts to the current error, providing immediate corrective action.  
- **Integral (I):** Accounts for the accumulation of past errors to eliminate steady-state errors.  
- **Derivative (D):** Predicts future error based on the rate of change, providing damping and stability.  

**In this robot**, the PID controller is used to adjust motor speeds and steering angles for smooth path following and precise obstacle avoidance. This ensures that movements are stable, efficient, and responsive to environmental changes.

---

This combination of visual detection, sensor feedback, mapping, and PID control allows the robot to operate autonomously through complex tasks such as lap tracking, obstacle avoidance, and precise parking.

**PID IN EV3 BLOCKS**

<div align="center">


---

## 💰 Material Cost Report 

| # | Component | Quantity | Unit Price (USD) | Total (USD) | Purchase Link |
|---|---|---|---|---|---|
| 1 | *45544 LEGO MINDSTORMS Education EV3 Core Set* | 1 | 470.00 | *470.00* | [Buy here](https://bricks-store.com/esp/item/585/66/45544-set-base-lego-mindstorms-education-ev3) |
| 2 | *OpenMV Cam H7 Plus* | 1 | 75.00 | *75.00* | [Buy here](https://openmv.io/products/openmv-cam-h7-plus) |
| 3 | *HC-SR04 Ultrasonic Sensor* | 5 | 3.00 | *15.00* | [Buy here](https://uelectronics.com/producto/sensor-ultrasonico-hc-sr04/) |
| 4 | *DFRobot URM09 Ultrasonic Sensor (Gravity Analog)* | 1 | 12.00 | *12.00* | [Buy here](https://wiki.dfrobot.com/URM09_Ultrasonic_Sensor_(Gravity_Analog)_SKU_SEN0307) |
| 5 | *Arduino Nano* | 2 | 8.00 | *16.00* | [Buy here](https://www.steren.com.mx/placa-de-desarrollo-nano.html) |
| 6 | *4x4 RGB LED Matrix (WS2812)* | 1 | 5.00 | *5.00* | [Buy here](https://mvelectronica.com/producto/matriz-de-led-rgb-4x4-ws2812-16bits-a-5v-led-5050) |
| 7 | *Mini 560 Step-Down Regulator* | 1 | 4.00 | *4.00* | [Buy here](https://uelectronics.com/producto/mini-560-regulador-step-down/) |
| 8 | *DFRobot Gravity BNO055* | 1 | 30.00 | *30.00* | [Buy here](https://es.aliexpress.com/i/32950220044.html) |
| 9 | *Digital Voltmeter* | 1 | 3.00 | *3.00* | [Buy here](https://www.amazon.com.mx/Volt%C3%ADmetro-pulgadas-volt%C3%ADmetro-protecci%C3%B3n-amarillo/dp/B07P1RV5B1/) |
| | *💵 Total Estimated Cost* | | | *650.00 USD* | |

---

**LEGO SET use**
| BLItemNo | PartName | Qty | Price per Piece (USD) | Total Price (USD) |
|---|---|-----|---|---|
| 2780 | Technic, Pin with Short Friction Ridges | 17 | 0.08 | 1.36 |
| 2905 | Technic, Liftarm, Modified Triangle Thin 3 x 5 with Full Supports | 2 | 0.05 | 0.10 |
| 32034 | Technic, Axle and Pin Connector Angled #2 - 180 degrees | 1 | 0.50 | 0.50 |
| 32062 | Technic, Axle 2L Notched | 16 | 0.01 | 0.16 |
| 32073 | Technic, Axle 5L | 6 | 0.75 | 4.50 |
| 4265c | Technic Bush 1/2 Smooth | 1 | 0.08 | 0.08 |
| 32184 | Technic, Axle and Pin Connector Perpendicular 3L with Center Pin Hole | 1 | 3.50 | 3.50 |
| 32269 | Technic, Gear 20 Tooth Double Bevel | 7 | 0.15 | 1.05 |
| 32278 | Technic, Liftarm Thick 1 x 15 | 4 | 2.59 | 10.36 |
| 32316 | Technic, Liftarm Thick 1 x 5 | 1 | 1.21 | 1.21 |
| 32523 | Technic, Liftarm Thick 1 x 3 | 2 | 0.70 | 1.40 |
| 32524 | Technic, Liftarm Thick 1 x 7 | 5 | 1.74 | 8.70 |
| 32526 | Technic, Liftarm, Modified Bent Thick L-Shape 3 x 5 | 5 | 1.77 | 8.85 |
| 3713 | Technic Bush | 4 | 0.14 | 0.56 |
| 39367pb01 | Wheel 56 x 14 Technic with Axle Hole and 8 Pin Holes with Molded Medium Azure Hard Rubber Tire Pattern | 4 | 3.00 | 12.00 |
| 40490 | Technic, Liftarm Thick 1 x 9 | 1 | 2.59 | 2.59 |
| 4274 | Technic, Pin 1/2 without Friction Ridges | 8 | 0.10 | 0.80 |
| 4519 | Technic, Axle 3L | 6 | 0.43 | 2.58 |
| 46372 | Technic, Gear 28 Tooth Double Bevel | 1 | 0.50 | 0.50 |
| 48989 | Technic, Pin Connector Perpendicular 3L with 4 Pins | 7 | 1.22 | 8.54 |
| 55013 | Technic, Axle 8L with Stop | 2 | 1.18 | 2.36 |
| 55615 | Technic, Pin Connector Perpendicular 3 x 3 Bent with 4 Pins | 2 | 1.90 | 3.80 |
| 6538c | Technic, Axle Connector 2L (Smooth with x Hole + Orientation) | 5 | 0.40 | 2.00 |
| 62520c01 | Technic, Universal Joint 3L | 2 | 0.54 | 1.08 |
| 62821a | Technic, Gear Differential 28 Tooth Bevel - Inner Tabs with Open Center | 2 | 2.85 | 5.70 |
| 64179 | Technic, Liftarm, Modified Frame Thick 5 x 7 Open Center | 2 | 5.30 | 10.60 |
| 64781 | Technic, Gear Rack 1 x 13 with Axle and Pin Holes | 1 | 3.13 | 3.13 |
| 6558 | Technic, Pin 3L with Friction Ridges | 14 | 0.31 | 4.34 |
| 6589 | Technic, Gear 12 Tooth Bevel | 6 | 0.29 | 1.74 |
| 71710 | Technic, Liftarm, Modified Perpendicular Holes Thick 1 x 15 | 2 | 1.00 | 2.00 |
| 73507 | Technic, Liftarm, Modified Perpendicular Holes Thick 1 x 11 | 2 | 1.00 | 2.00 |
| 87083 | Technic, Axle 4L with Stop | 1 | 0.59 | 0.59 |
| 94925 | Technic, Gear 16 Tooth - Axle Hole with Closed Sides | 4 | 0.70 | 2.80 |
| 99455 | Electric, Motor EV3, Medium | 3 | 35.00 | 105.00 |
| 99773 | Technic, Liftarm, Modified Triangle Thin 3 x 5 with Short Supports | 6 | 1.20 | 7.20 |
| **95646** | **LEGO MINDSTORMS EV3 Intelligent Brick** | 1 | 245.00 | 245.00 |
| **—** | **TOTAL GENERAL** | **—** | **—** | **488.92 USD** |

## References
- [WRO 2025 Future Engineers – General Rules PDF](https://wro-association.org/wp-content/uploads/WRO-2025-Future-Engineers-Self-Driving-Cars-General-Rules.pdf)
- [Hardware Developer Kit PDF](https://github.com/user-attachments/files/22328277/hardware_developer_kit.pdf)

---

*End of README.md for Team Los Grises Superiores – WRO 2025 Future Engineers*

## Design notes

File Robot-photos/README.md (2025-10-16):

<div align="center">

| Front | Back |
|:--:|:--:|
| Front |   |

| Bottom | Top |
|:--:|:--:|
| Top | Bottom |

| Left | Right |
|:--:|:--:|
| Left | Right |

</div>

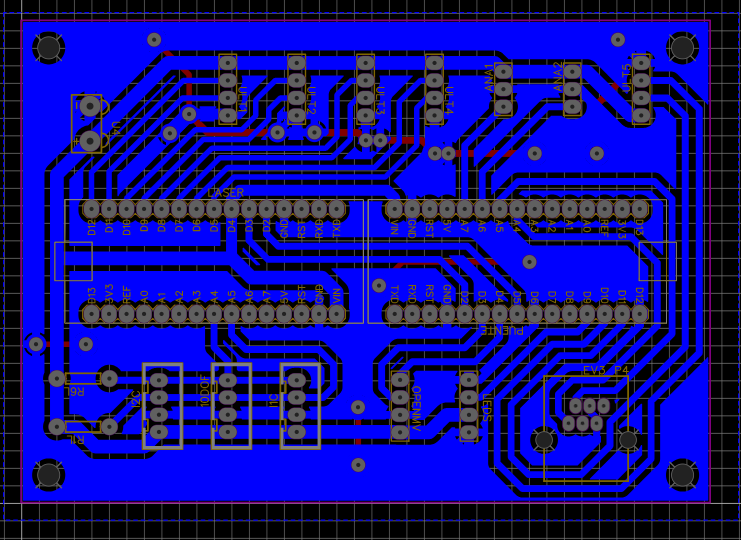
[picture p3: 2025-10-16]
Schemes/arduinos PCB design.png

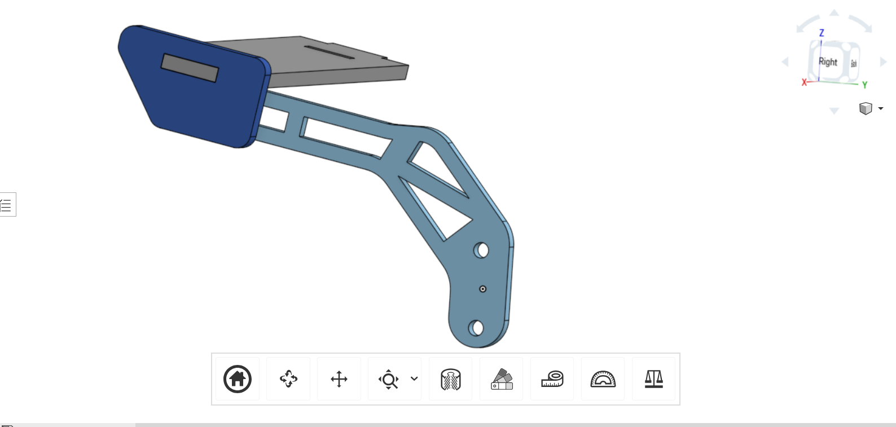
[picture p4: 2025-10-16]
Models/aleron design.png

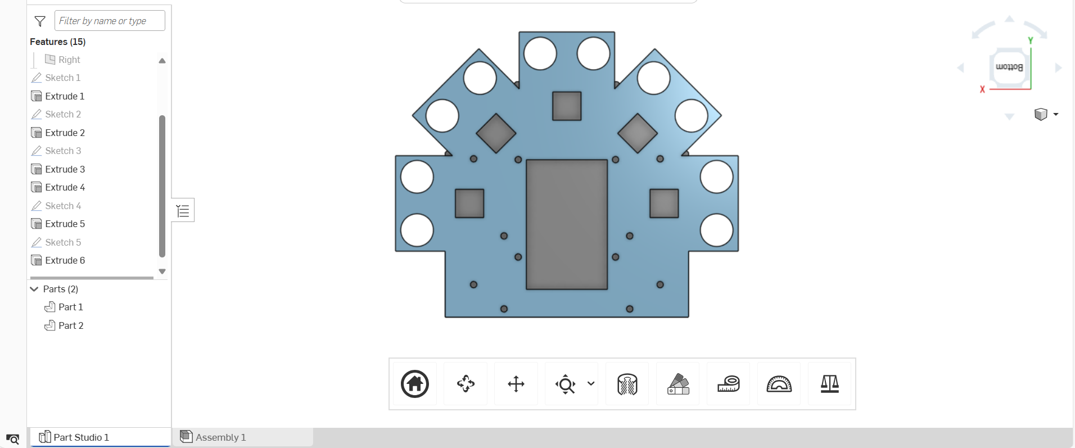
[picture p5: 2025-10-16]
Models/ultras design.png

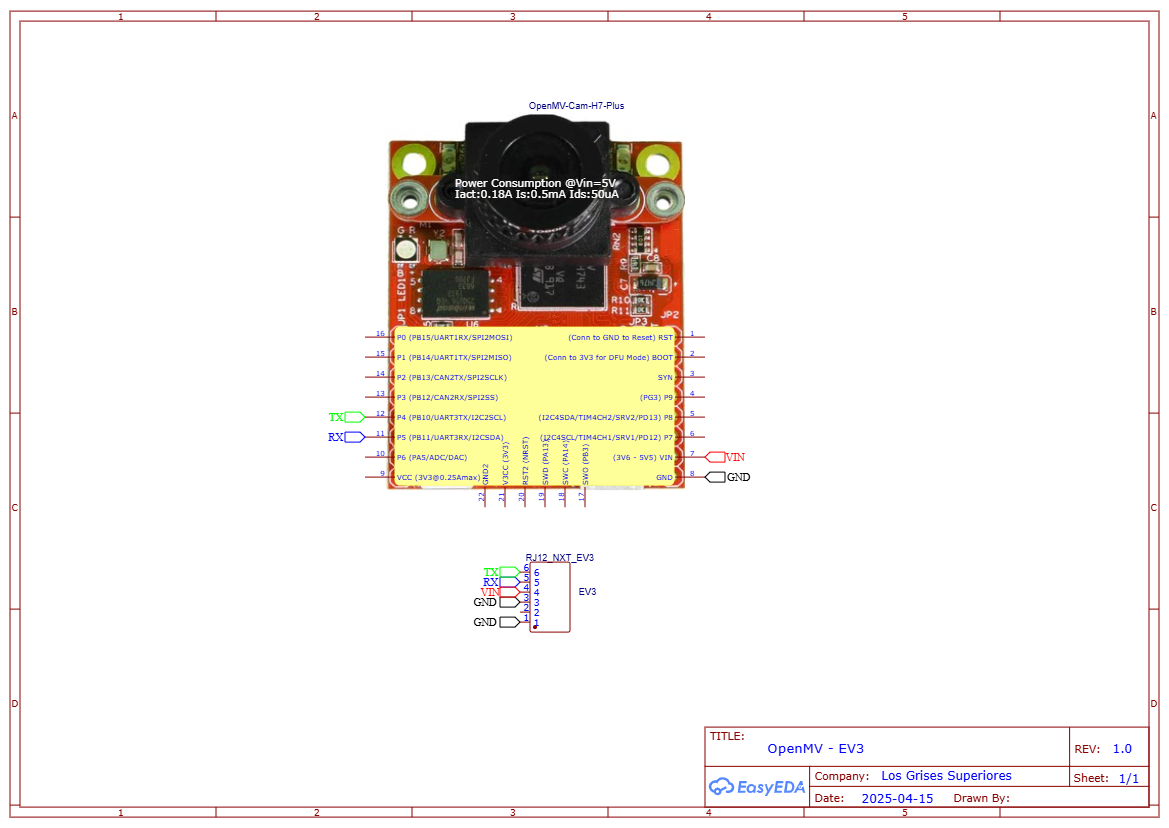
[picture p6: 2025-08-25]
Schemes/Schematic_open-mv_2025-08-24.png

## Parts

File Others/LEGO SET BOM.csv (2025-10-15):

BLItemNo | ElementId | LdrawId | PartName | BLColorId | LDrawColorId | ColorName | ColorCategory | Qty | Weight
2780 | 6279875 | 2780.dat | Technic, Pin with Short Friction Ridges | 11 | 0 | Black | Solid Colors | 17 | 0.16
2905 | 4211653 | 2905.dat | Technic, Liftarm, Modified Triangle Thin 3 x 5 with Full Supports | 86 | 71 | Light Bluish Gray | Solid Colors | 2 | 1.16
32034 | 6271869 | 32034.dat | Technic, Axle and Pin Connector Angled #2 - 180 degrees | 11 | 0 | Black | Solid Colors | 1 | 0.68
32062 | 4142865 | 32062.dat | Technic, Axle 2L Notched | 5 | 4 | Red | Solid Colors | 16 | 0.26
32073 | 4211639 | 32073.dat | Technic, Axle 5L | 86 | 71 | Light Bluish Gray | Solid Colors | 6 | 0.66
4265c | 6271167 | 32123a.dat | Technic Bush 1/2 Smooth | 3 | 14 | Yellow | Solid Colors | 1 | 0.1
32184 | 6276951 | 32184.dat | Technic, Axle and Pin Connector Perpendicular 3L with Center Pin Hole | 11 | 0 | Black | Solid Colors | 1 | 0.64
32269 | 6346535 | 32269.dat | Technic, Gear 20 Tooth Double Bevel | 11 | 0 | Black | Solid Colors | 7 | 1.4
32278 | 4542573 | 32278.dat | Technic, Liftarm Thick 1 x 15 | 11 | 0 | Black | Solid Colors | 4 | 4
32316 | 4211651 | 32316.dat | Technic, Liftarm Thick 1 x 5 | 86 | 71 | Light Bluish Gray | Solid Colors | 1 | 1.21
32523 | 4142822 | 32523.dat | Technic, Liftarm Thick 1 x 3 | 11 | 0 | Black | Solid Colors | 2 | 0.7
32524 | 4495930 | 32524.dat | Technic, Liftarm Thick 1 x 7 | 86 | 71 | Light Bluish Gray | Solid Colors | 3 | 1.74
32524 | 4495935 | 32524.dat | Technic, Liftarm Thick 1 x 7 | 11 | 0 | Black | Solid Colors | 2 | 1.74
32526 | 4142823 | 32526.dat | Technic, Liftarm, Modified Bent Thick L-Shape 3 x 5 | 11 | 0 | Black | Solid Colors | 5 | 1.77
3713 | 6275844 | 3713.dat | Technic Bush | 86 | 71 | Light Bluish Gray | Solid Colors | 4 | 0.14
39367pb01 | 6460453 | 39367pb01.dat | Wheel 56 x 14 Technic with Axle Hole and 8 Pin Holes with Molded Medium Azure Hard Rubber Tire Pattern | 11 | 0 | Black | Solid Colors | 4 | 0
40490 | 4645732 | 40490.dat | Technic, Liftarm Thick 1 x 9 | 11 | 0 | Black | Solid Colors | 1 | 2.59
4274 | 4211483 | 4274.dat | Technic, Pin 1/2 without Friction Ridges | 86 | 71 | Light Bluish Gray | Solid Colors | 8 | 0.095
4519 | 4211815 | 4519.dat | Technic, Axle 3L | 86 | 71 | Light Bluish Gray | Solid Colors | 6 | 0.43
46372 | 6259270 | 46372.dat | Technic, Gear 28 Tooth Double Bevel | 86 | 71 | Light Bluish Gray | Solid Colors | 1 | 0
48989 | 6282158 | 48989.dat | Technic, Pin Connector Perpendicular 3L with 4 Pins | 86 | 71 | Light Bluish Gray | Solid Colors | 7 | 1.22
55013 | 4499858 | 55013.dat | Technic, Axle 8L with Stop | 85 | 72 | Dark Bluish Gray | Solid Colors | 2 | 1.18
55615 | 6313453 | 55615.dat | Technic, Pin Connector Perpendicular 3 x 3 Bent with 4 Pins | 86 | 71 | Light Bluish Gray | Solid Colors | 2 | 1.9
6538c | 4512363 | 59443.dat | Technic, Axle Connector 2L (Smooth with x Hole + Orientation) | 11 | 0 | Black | Solid Colors | 5 | 0.4
62520c01 | 6335279 | 61903.dat | Technic, Universal Joint 3L | 86 | 71 | Light Bluish Gray | Solid Colors | 2 | 0.54
62821a |  | 62821.dat | Technic, Gear Differential 28 Tooth Bevel - Inner Tabs with Open Center | 86 | 71 | Light Bluish Gray | Solid Colors | 2 | 2.85
64179 | 6016154 | 64179.dat | Technic, Liftarm, Modified Frame Thick 5 x 7 Open Center | 11 | 0 | Black | Solid Colors | 2 | 5.3
64179 | 4539880 | 64179.dat | Technic, Liftarm, Modified Frame Thick 5 x 7 Open Center | 86 | 71 | Light Bluish Gray | Solid Colors | 2 | 5.3
64781 | 6302830 | 64781.dat | Technic, Gear Rack 1 x 13 with Axle and Pin Holes | 11 | 0 | Black | Solid Colors | 1 | 3.13
6558 | 6299413 | 6558.dat | Technic, Pin 3L with Friction Ridges | 7 | 1 | Blue | Solid Colors | 14 | 0.31
6589 | 4565452 | 6589.dat | Technic, Gear 12 Tooth Bevel | 2 | 19 | Tan | Solid Colors | 6 | 0.29
71710 | 6321716 | 71710.dat | Technic, Liftarm, Modified Perpendicular Holes Thick 1 x 15 | 11 | 0 | Black | Solid Colors | 2 | 0
73507 | 6330585 | 73507.dat | Technic, Liftarm, Modified Perpendicular Holes Thick 1 x 11 | 11 | 0 | Black | Solid Colors | 2 | 0
87083 | 6083620 | 87083.dat | Technic, Axle 4L with Stop | 85 | 72 | Dark Bluish Gray | Solid Colors | 1 | 0.59
94925 | 4640536 | 94925.dat | Technic, Gear 16 Tooth - Axle Hole with Closed Sides | 86 | 71 | Light Bluish Gray | Solid Colors | 4 | 0.7
99455 |  | 99455.dat | Electric, Motor EV3, Medium | 86 | 71 | Light Bluish Gray | Solid Colors | 3 | 38.3
99773 | 6331428 | 99773.dat | Technic, Liftarm, Modified Triangle Thin 3 x 5 with Short Supports | 86 | 71 | Light Bluish Gray | Solid Colors | 6 | 1.2
Total qty | Total Weight
155 | 246.41

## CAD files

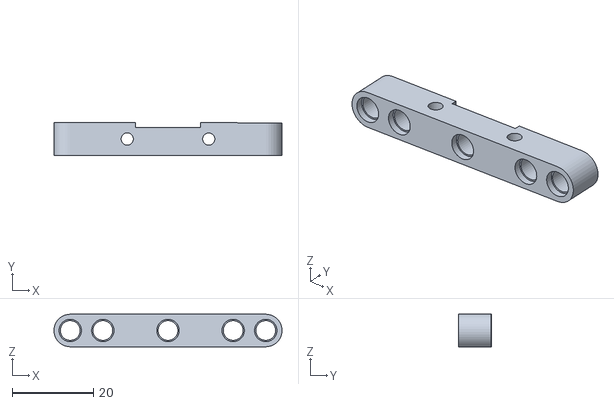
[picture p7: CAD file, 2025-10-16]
Models/Piezasensorlaser.STL
56.0 x 8.10 x 8.00

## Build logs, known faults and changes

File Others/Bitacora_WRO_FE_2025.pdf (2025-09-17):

## FUTURE ENGINEERS

## LOS GRISES SUPERIORES

Introducción.

Nuestro robot, desarrollado por estudiantes de niveles superiores para WRO Future

engineers, combina un EV3 de LEGO como controlador principal y dos cámaras OpenMV

para visión. Detecta colores clave (blanco, rojo, verde, azul y naranja) mediante calibración

LAB, empleando cuatro ROIs (bajo, medio, alto y negro) para seguimiento de línea,

regulación del ancho del pasillo, detección de obstáculos y alerta de colisión. La posición X

de los blobs determina la maniobra de evasión según las reglas de competencia (rojo =

derecha, verde = izquierda).

Diseñado de manera compacta y simétrica, con cuatro ruedas y tres motores, asegura un

desplazamiento estable y preciso. La navegación integra la información visual con la lógica

del EV3, combinando seguimiento de línea, control de pasillo y evasión de obstáculos. Todo

el desarrollo, realizado mediante pruebas y ajustes continuos, resultó en un robot confiable,

eficiente y listo para competir.

1. Equipo.

Erick Daniel Guerrero Uresti. Comencé a participar en torneos de robótica desde el 2016 al 2019 obteniendo 2 segundos lugares en el torneo mexicano de robótica, debido a la pandemia Covid19 no pude seguir compitiendo si no hasta el 2024 como coach en TMR y WRO obteniendo pase al internacional actualmente estudio mi último año de ingeniería en mecatrónica.

Paulina Ibarra Martínez. Tres años siendo parte del club de robótica de la Escuela Normal Superior “Profr. Moisés Sáenz Garza”, participación en dos torneos mexicanos de robótica obteniendo el 5 lugar en el último, siendo coach junior a partir del 2024, obteniendo tercer lugar en el WRO 2024 y primer lugar nacional en el torneo mexicano de robótica 2025.

2. Visión.

El sistema de visión constituye uno de los componentes fundamentales del robot, ya que

permite la interpretación del entorno de competencia y la toma de decisiones en tiempo

real. Para este fin se empleó una cámara OpenMV, configurada y optimizada durante

distintas etapas del proyecto. El desarrollo incluyó procesos de calibración de colores,

definición y evolución de las regiones de interés (ROIs), y el diseño de estrategias para

la detección de obstáculos y prevención de colisiones.

### 2.1 Calibración

Durante las primeras pruebas se detectaron inestabilidades en la identificación de colores

debido a variaciones de luz ambiental. Para resolverlo, se fijaron parámetros de la cámara

como auto-gain, auto-white balance y exposición, garantizando una detección más

estable. Además, se realizó un ajuste progresivo de umbrales LAB para colores clave de

la pista: blanco, rojo, verde, azul y naranja. Este proceso permitió que el sistema

funcionara con mayor consistencia en diferentes condiciones de iluminación.

### 2.2 Evolución de las regiones (ROIs)

- Inicio: Se empleó un ROI central dinámico anclado al piso blanco, enfocado en

el seguimiento de la línea principal.

- Propuesta de mejora: Se consideró el uso de ROIs trapezoidales para abarcar tanto

el camino como los pilares.

- Septiembre: Se incorporó un sistema de tres ROIs horizontales (bajo, medio y

alto), inicialmente fijos, y posteriormente transformados en dinámicos, siempre

ajustando su borde inferior al piso blanco. Estos ROIs permitieron una mejor

detección de pasillos amplios o estrechos, además de brindar soporte en curvas.

- ROI adicional: Se introdujo un ROI negro con la función específica de alertar

colisiones, reemplazando la detección directa de pilares en casos críticos.

Actualmente, el robot utiliza cuatro ROIs principales:

- ROI Bajo: Seguimiento de la línea y detección de colores cercanos al piso.
- ROI Medio: Identificación de obstáculos intermedios (rojo, verde, naranja).
- ROI Alto: Apoyo en curvas y detección de obstáculos lejanos.
- ROI Negro: Alerta de colisión en caso de detección de áreas oscuras.
Fecha | Configuración de ROIs | Objetivo principal
20 de agosto | ROI central dinámico anclado al piso blanco. | Seguimiento inicial de la línea y detección de colores básicos.
27 de agosto | Propuesta de ROIs trapezoidales. | Ampliar la cobertura para abarcar camino y pilares.
3 de septiembre | ROIs dinámicos combinados con un ROI de altura. | Seguimiento de línea y cálculo de distancia libre.
5 de septiembre | Tres ROIs horizontales fijos (bajo, medio, alto). | Diferenciar pasillos amplios o estrechos mediante detección de colores.
8 de septiembre | Tres ROIs horizontales dinámicos + ROI negro. | Mejorar la detección de rojo, verde y naranja; añadir alerta de colisión.
9 de septiembre | ROIs con estrategia de compensación en curvas. | Evitar pérdida de pilares lejanos; detección simultánea de rojo, verde y blanco.
11 de septiembre | ROIs refinados para entregar coordenada X en base Y. | Detección precisa de esquinas de color y soporte en curvas.

### 2.3 Estrategias de detección y evasión

El sistema de visión también se diseñó para soportar la lógica de evasión de obstáculos.

Para ello, se empleó la coordenada X en la base del blob como métrica principal, lo que

permitió una detección más confiable que el área del objeto, la cual en ocasiones generaba

datos inconsistentes. Adicionalmente, la lógica incorporada al EV3 utiliza las reglas de

competencia (pilar rojo = giro a la derecha, pilar verde = giro a la izquierda) para definir

la maniobra adecuada de evasión.

2.4 Problemas y soluciones.

Problema identificado | Solución implementada
Variaciones de luz en la pista generaban detecciones inestables. | Se fijaron los parámetros de auto-gain, auto-white balance y exposición en la cámara OpenMV, asegurando estabilidad en la detección.
En curvas, el robot perdía de vista los pilares más lejanos. | Se introdujo una estrategia de compensación con la posición base del blob y se ampliaron los ROIs dinámicos para mantener cobertura.
El robot detectaba áreas muy grandes en los blobs de color, provocando datos confusos. | Se adoptó la coordenada X en la base del blob como métrica principal y se mantuvo el área solo como referencia secundaria.
Los scripts de OpenMV eran redundantes y complicaban la integración con EV3. | Se unificaron los envíos de datos en slots LPF2, eliminando redundancias como PRINT_EVERY y SEND_EVERY.
El seguidor de línea no era reactivo a los cambios en el ancho del pasillo. | Se incorporó el ancho del pasillo como variable proporcional de corrección (ajuste de KP en el EV3).
Riesgo de choque cuando el robot no reconocía pilares correctamente. | Se sustituyó el ROI de pilares por un ROI negro, encargado de alertar colisiones en la trayectoria.
3. Control.

El sistema de control del robot está diseñado para garantizar un desplazamiento estable

dentro de la pista, integrando la información visual obtenida por la cámara OpenMV con

la lógica implementada en el controlador EV3. La estrategia de navegación se basa en

tres pilares: seguimiento de línea, regulación del ancho de pasillo y evasión de obstáculos.

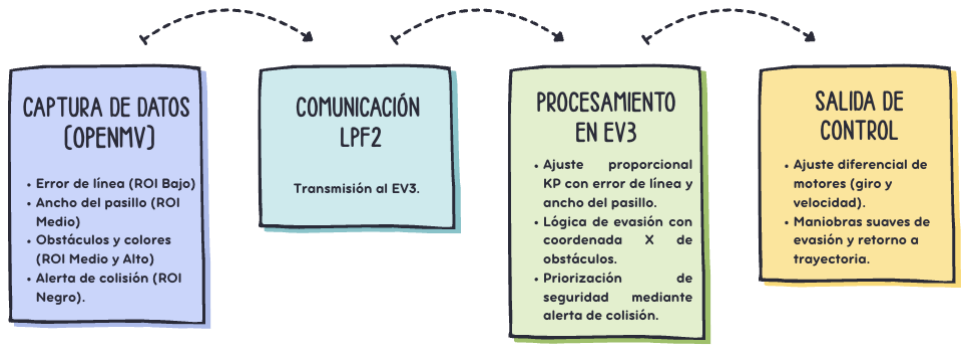
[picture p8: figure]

3.1 Seguimiento de linea.

Para mejorar la respuesta, se incorporó un esquema de ROIs horizontales dinámicos, que

permiten identificar la posición relativa de la línea en diferentes alturas de la imagen. El

error de posición se traduce en una señal proporcional dentro del EV3, donde el KP inicial

fue configurado en 1 y ajustado posteriormente para mejorar la sensibilidad en curvas y

rectas.

3.2 Regulación ancho de pasillo.

Una de las mejoras clave fue la incorporación del ancho del pasillo como métrica de

control. A partir de los datos enviados desde la OpenMV (ancho detectado en ROIs

inferiores), se integró un cálculo proporcional dentro del controlador del EV3. Esto

permitió que el robot ajustara su trayectoria en función del espacio libre disponible,

logrando una navegación más reactiva y adaptada a variaciones en el entorno.

3.3 Evasión de obstáculos.

La evasión de obstáculos se diseñó considerando las reglas de competencia: pilar rojo

implica giro a la derecha, pilar verde implica giro a la izquierda. Para determinar el lado

de evasión, el robot utiliza la diferencia entre la posición X detectada en la cámara y un

X target predefinido, lo que permite definir de forma confiable el sentido de maniobra.

Posteriormente, el robot ejecuta la evasión mediante una trayectoria suave que incluye:

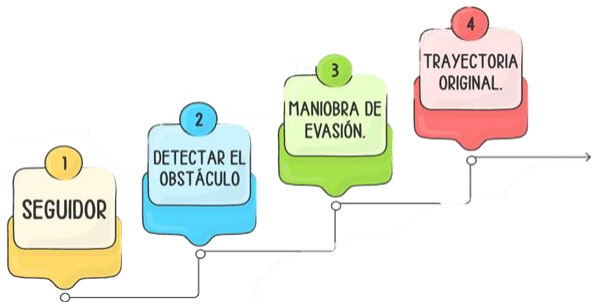
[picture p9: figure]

3.4 Integración y comunicación.

La comunicación entre la OpenMV y el EV3 se realiza mediante el protocolo LPF2, en

el que se unificaron los datos transmitidos para simplificar la integración. Se eliminó la

redundancia de funciones internas como PRINT_EVERY y SEND_EVERY, centralizando

los envíos de métricas en slots específicos. Las principales variables enviadas fueron:

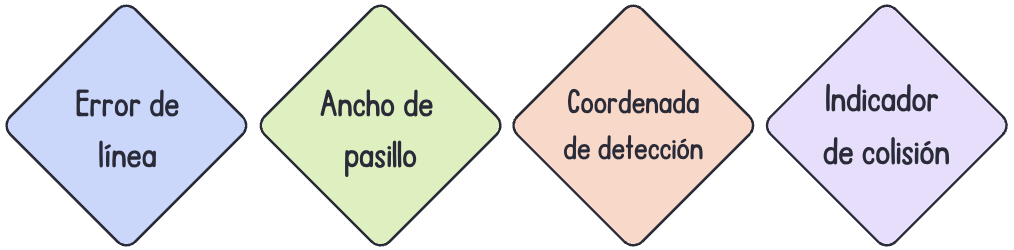
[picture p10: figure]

3.5 Sensores y métricas.

Sensor / Fuente | Métrica extraída | Uso en el sistema de control
OpenMV – ROI Bajo | Error de línea (posición relativa del piso) | Seguimiento de trayectoria principal.
OpenMV – ROI Medio | Ancho de pasillo y colores intermedios (rojo, verde, naranja) | Regulación proporcional y anticipación de obstáculos.
OpenMV – ROI Alto | Posición de obstáculos lejanos | Soporte en curvas y preparación de evasión.
OpenMV – ROI Negro | Detección de áreas oscuras (colisión) | Alerta de choque, envío de indicador binario al EV3.
OpenMV – Blobs de color | Coordenada X en base Y del objeto detectado | Determinación del lado de evasión (rojo = derecha, verde = izquierda).
EV3 – Motor encoders | Velocidad y distancia recorrida | Control de velocidad y desplazamiento suave en maniobras.
EV3 – Lógica interna | Variable proporcional (KP) | Corrección dinámica en curvas y rectas.
4. Conclusión.

El desarrollo de este robot permitió integrar sistemas de visión y control de manera

eficiente, logrando un desplazamiento estable, detección precisa de colores y evasión

de obstáculos.

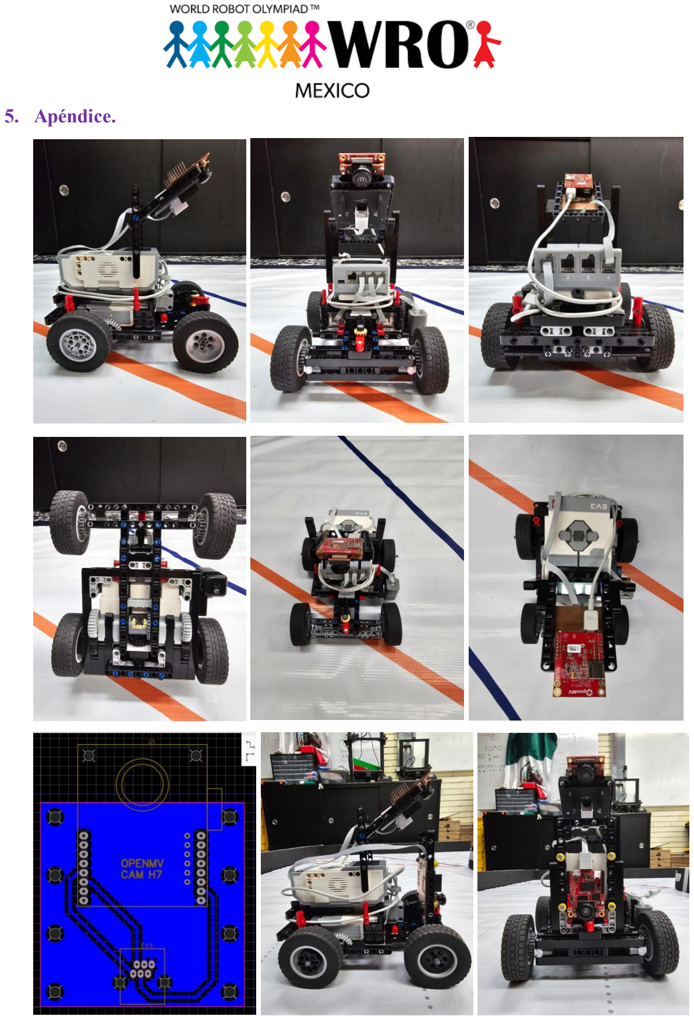
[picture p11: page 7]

5. Apéndice.

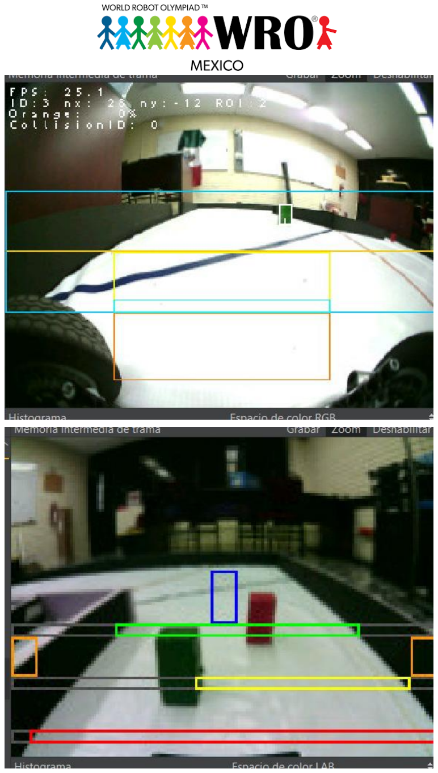
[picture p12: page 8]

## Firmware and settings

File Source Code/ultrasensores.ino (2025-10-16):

// ---- Nano (ATmega328P): 4x HC-SR04 + BNO055 -> UART D2/D3 (CSV + Laps) ----
// CSV format: l90, l45, r45, r90, laps
// Requirements: HC-SR04 + BNO055 (without Adafruit libraries)

#include <Wire.h>
#include <SoftwareSerial.h>
#include <NewPing.h>

// ------------------- ULTRASONIC CONFIGURATION -------------------
// Maximum distance in cm for ultrasonic readings
#define MAX_DISTANCE 200

// Ultrasonic sensor pin configuration: trigger, echo, max distance
NewPing r90(12, 11, MAX_DISTANCE);
NewPing r45(10, 9, MAX_DISTANCE);
NewPing l45(8, 7, MAX_DISTANCE);
NewPing l90(6, 5, MAX_DISTANCE);

// ------------------- LAP DETECTION CONFIGURATION -------------------
#define LAPS_METHOD 3 // Method 3 combines rotation and angular gate detection

// Defines how many ticks correspond to one full rotation (360° * 16)
const long LAP_TICKS16 = 360L * 16;
// Minimum time (ms) between laps to avoid false detections
const unsigned long LAP_MIN_MS = 3000;

const int GATE_HALF_WIDTH = 15;
const int GATE_HYST = 5;
int c = 0;

// ------------------- UART COMMUNICATION --------------------------
// Software serial communication: TX = D3 (to master EV3)
SoftwareSerial link(2, 3);  

// ------------------- BNO055 MINIMAL IMPLEMENTATION ----------------
// Minimal I2C communication to read heading directly from BNO055 sensor
namespace BNO {
static uint8_t ADDR = 0x28;
const uint8_t REG_CHIP_ID = 0x00;
const uint8_t REG_EUL_HEADING_LSB = 0x1A;
const uint8_t REG_OPR_MODE = 0x3D;
const uint8_t REG_SYS_TRIG = 0x3F;
const uint8_t REG_PAGE_ID = 0x07;
const uint8_t REG_PWR_MODE = 0x3E;
const uint8_t REG_UNIT_SEL = 0x3B;
const uint8_t OPR_CONFIG = 0x00;
const uint8_t OPR_NDOF = 0x0C;
const uint8_t PWR_NORMAL = 0x00;

// --- Low-level I2C write ---
inline void write8(uint8_t reg, uint8_t val) {
  Wire.beginTransmission(ADDR);
  Wire.write(reg);
  Wire.write(val);
  Wire.endTransmission();
}

// --- Low-level I2C read (multiple bytes) ---
inline void readLen(uint8_t reg, uint8_t *buf, uint8_t len) {
  Wire.beginTransmission(ADDR);
  Wire.write(reg);
  Wire.endTransmission();
  Wire.requestFrom((int)ADDR, (int)len);
  for (uint8_t i = 0; i < len && Wire.available(); i++) buf[i] = Wire.read();
}

// --- Read a single byte from a register ---
inline uint8_t read8(uint8_t reg) {
  uint8_t v = 0;
  readLen(reg, &v, 1);
  return v;
}

// --- Detect valid BNO055 I2C address (0x28 or 0x29) ---
bool probeAny() {
  delay(700);
  uint8_t posibles[2] = { 0x28, 0x29 };
  for (uint8_t i = 0; i < 2; i++) {
    ADDR = posibles[i];
    for (uint8_t j = 0; j < 10; j++) {
      delay(20);
      if (read8(REG_CHIP_ID) == 0xA0) return true;
    }
  }
  return false;
}

// --- Initialize BNO055 without using external libraries ---
bool begin() {
  if (!probeAny()) return false;
  write8(REG_OPR_MODE, OPR_CONFIG);
  delay(25);
  write8(REG_SYS_TRIG, 0x20);
  delay(700);
  if (!probeAny()) return false;
  write8(REG_PAGE_ID, 0x00);
  delay(5);
  write8(REG_PWR_MODE, PWR_NORMAL);
  delay(10);
  write8(REG_UNIT_SEL, 0x00);
  delay(10);
  write8(REG_OPR_MODE, OPR_NDOF);
  delay(50);

  // Wait until valid heading data is available
  uint32_t t0 = millis();
  while (millis() - t0 < 300) {
    uint8_t b[2];
    readLen(REG_EUL_HEADING_LSB, b, 2);
    if (b[0] || b[1]) break;
    delay(10);
  }
  return true;
}

// --- Read 16-bit heading value (yaw angle) ---
inline int16_t readHeading16() {
  uint8_t b[2];
  readLen(REG_EUL_HEADING_LSB, b, 2);
  return (int16_t)((uint16_t)b[0] | ((uint16_t)b[1] << 8));
}
}  // namespace BNO

// ------------------- ANGLE UTILITIES -----------------
static inline int16_t yawDelta16(int16_t cur, int16_t prev) {
  int16_t d = cur - prev;
  while (d > 2880) d -= 5760;
  while (d < -2880) d += 5760;
  return d;
}
static inline int angDiffDeg(int a, int b) {
  int d = a - b;
  while (d > 180) d -= 360;
  while (d < -180) d += 360;
  return d;
}

// ------------------- STATE VARIABLES --------------------
int16_t yaw_prev16 = 0;
bool yaw_has_prev = false;
long yaw_accum16 = 0;
long yaw_sinceLap16 = 0;
int lap_count = 0;
unsigned long lastLapMs = 0;
int gate0_deg = 0;
bool gate_armed = false;
bool yaw_pending = false;
bool gate_pending = false;
bool bno_ok = false;

// ------------------- LAP CALCULATION FUNCTIONS -------------------
inline bool timeOk() {
  return (millis() - lastLapMs) > LAP_MIN_MS;
}
inline void countedNow() {
  lastLapMs = millis();
}

// --- Detect lap based on accumulated yaw angle ---
void tryCountLapAccumYaw() {
#if (LAPS_METHOD == 1) || (LAPS_METHOD == 3)
  if (labs(yaw_sinceLap16) >= LAP_TICKS16) {
#if (LAPS_METHOD == 1)
    if (timeOk()) {
      lap_count++;
      countedNow();
    }
    yaw_sinceLap16 %= LAP_TICKS16;
#else
    yaw_pending = true;
    yaw_sinceLap16 %= LAP_TICKS16;
#endif
  }
#endif
}

// --- Detect lap based on gate crossing (angle threshold) ---
void tryCountLapGate(int deg_now) {
#if (LAPS_METHOD == 2) || (LAPS_METHOD == 3)
  int dgate = angDiffDeg(deg_now, gate0_deg);
  if (!gate_armed && abs(dgate) > (GATE_HALF_WIDTH + GATE_HYST)) gate_armed = true;
  if (gate_armed && abs(dgate) <= GATE_HALF_WIDTH) {
#if (LAPS_METHOD == 2)
    if (timeOk()) {
      lap_count++;
      countedNow();
    }
    gate_armed = false;
#else
    gate_pending = true;
    gate_armed = false;
#endif
  }
#endif
}

// --- Combine both lap detection methods ---
void resolveLapMethod3() {
#if (LAPS_METHOD == 3)
  if (yaw_pending && gate_pending && timeOk()) {
    lap_count++;
    countedNow();
    yaw_pending = false;
    gate_pending = false;
  }
#endif
}

// ------------------- ULTRASONIC FILTER -------------------
// Median + average filter to remove outliers from sensor readings
#define READS_PER_SENSOR 5
unsigned int filteredPing(NewPing &sensor) {
  int vals[READS_PER_SENSOR];
  int valid = 0;

  // Perform multiple readings
  for (int i = 0; i < READS_PER_SENSOR; i++) {
    unsigned int uS = sensor.ping();
    if (uS > 0) vals[valid++] = uS / US_ROUNDTRIP_CM;
    delay(10);
  }
  if (valid == 0) return 0;

  // Sort values (simple insertion sort)
  for (int i = 1; i < valid; i++) {
    int key = vals[i];
    int j = i - 1;
    while (j >= 0 && vals[j] > key) {
      vals[j + 1] = vals[j];
      j--;
    }
    vals[j + 1] = key;
  }

  // Median-based filter: remove outliers beyond ±15 cm
  int median = vals[valid / 2];
  int sum = 0, count = 0;
  for (int i = 0; i < valid; i++) {
    if (abs(vals[i] - median) < 15) {
      sum += vals[i];
      count++;
    }
  }
  return (count > 0) ? (sum / count) : median;
}

// ------------------- SERIAL DATA -------------------
String line = "";

// ------------------- SETUP -------------------
void setup() {
  Serial.begin(9600);
  link.begin(115200);
  Wire.begin();

  // Initialize BNO055
  bno_ok = BNO::begin();
  if (!bno_ok) link.println(F("ERR_BNO"));
  
  // Save initial heading as gate reference
  if (bno_ok) {
    int16_t h16 = BNO::readHeading16();
    gate0_deg = (int)((h16 + 8) / 16);
  }

  // Print CSV header
  link.println(F("l90,l45,r45,r90,lap_count"));
}

// ------------------- MAIN LOOP -------------------
void loop() {

  // --- Check for serial command to reset laps ---
  if (link.available()) {
    c = link.read();
  } else {
    c = 0;
  }
  if (c == 10) {  // If newline received, reset counters
    lap_count = 0;
    yaw_accum16 = 0;
    yaw_sinceLap16 = 0;
    yaw_has_prev = false;
    gate_armed = false;
    yaw_pending = false;
    gate_pending = false;
  }

  Serial.println(lap_count);

  // --- Filtered ultrasonic readings ---
  int l90b = filteredPing(l90);
  int l45b = filteredPing(l45);
  int r45b = filteredPing(r45);
  int r90b = filteredPing(r90);

  // --- Heading and lap calculation from BNO055 ---
  int pos_deg = 0, deg_now = 0;
  if (bno_ok) {
    int16_t yaw_now16 = BNO::readHeading16();
    deg_now = (int)((yaw_now16 + 8) / 16);
    if (!yaw_has_prev) {
      yaw_prev16 = yaw_now16;
      yaw_has_prev = true;
    } else {
      int16_t d16 = yawDelta16(yaw_now16, yaw_prev16);
      yaw_accum16 += (long)d16;
      yaw_sinceLap16 += (long)d16;
      yaw_prev16 = yaw_now16;
      tryCountLapAccumYaw();
      tryCountLapGate(deg_now);
      resolveLapMethod3();
    }
    pos_deg = (int)(yaw_accum16 / 16L);
  }

  // --- Send CSV line over UART ---
  link.print(l90b);
  link.print(',');
  link.print(l45b);
  link.print(',');
  link.print(r45b);
  link.print(',');
  link.print(r90b);
  link.print(',');
  link.println(lap_count);

  delay(40);
}

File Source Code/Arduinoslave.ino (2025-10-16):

#include <Wire.h>
#define SLAVE_ADDRESS 0x04
#include <SoftwareSerial.h>
#include <Adafruit_NeoPixel.h>
#include <NewPing.h>

Adafruit_NeoPixel matriz(16, 9, NEO_GRB + NEO_KHZ800);
NewPing frontU(11, 10, 200);

int POT_LUZ = 10;
bool linkSent = false;  // global flag for first-time data sending

// Sensors
int front;  // Local front HC-SR04
int l45;
int r45;
int l90;
int r90;
int laps;
float As6;
float As7;
float rearanalog;
float rearanalog2;

// Mapped data
int frontbyte;
int l45byte;
int r45byte;
int l90byte;
int r90byte;
int A6byte;
int A7byte;

int mind_n_DATO_1;
int8_t tx_byte = 0;

SoftwareSerial sensorLink(2, 5);  // RX=D2, TX=D5
String line = "";

void setup() {
  sensorLink.begin(115200);  // Communication with Nano sensors

  Wire.begin(SLAVE_ADDRESS);  // Initialize I2C as slave
  Wire.onRequest(sendData);
  Wire.onReceive(onreceiveEvent);

  matriz.begin();
  matriz.show();
  int rgb = map(POT_LUZ, 0, 100, 0, 255);
  matriz.fill(matriz.Color(rgb, rgb, rgb), 0, 16);
  matriz.show();
}

void loop() {
  // Local front sensor
  front = frontU.ping_cm();
  As6 = analogRead(A6);
  rearanalog = (As6 * 500) / 1023;
  As7 = analogRead(A7);
  rearanalog2 = (As7 * 500) / 1023;

  // Read CSV line from Nano
  while (sensorLink.available()) {
    char c = sensorLink.read();
    if (c == '\n') {
      processLine(line);
      line = "";
    } else if (c != '\r') {
      line += c;
    }
  }

  // Map data to ranges (-100,100) or (-127,127)
  frontbyte = map(front, 0, 200, -100, 100);
  l45byte = map(l45, 0, 200, -100, 100);
  r45byte = map(r45, 0, 200, -100, 100);
  l90byte = map(l90, 0, 200, -100, 100);
  r90byte = map(r90, 0, 200, -100, 100);
  A6byte = map(rearanalog, 0, 500, -127, 127);
  A7byte = map(rearanalog2, 0, 500, -127, 127);
}

void sendData() {
  switch (mind_n_DATO_1) {
    case 1: tx_byte = l90byte; break;
    case 2: tx_byte = l45byte; break;
    case 3: tx_byte = frontbyte; break;
    case 4: tx_byte = r45byte; break;
    case 5: tx_byte = r90byte; break;
    case 6:
      if (!linkSent) {         // only if it hasn't been sent before
        sensorLink.write(10);  // send the data
        linkSent = true;       // mark as sent
      }
      tx_byte = 0;
      break;
    case 7: tx_byte = laps; break;
    case 8: tx_byte = A6byte; break;
    case 9: tx_byte = A7byte; break;
    default:
      tx_byte = 0;
      break;
  }

  // Reset flag if leaving case 6
  if (mind_n_DATO_1 != 6) linkSent = false;

  Wire.write((uint8_t)tx_byte);
}

void onreceiveEvent() {
  while (Wire.available()) {
    mind_n_DATO_1 = (Wire.read());
  }
}

void processLine(String l) {
  // CSV with 5 values: l90, l45, r45, r90, laps
  int values[5];
  int idx = 0;
  char *token;
  char buf[50];
  l.toCharArray(buf, sizeof(buf));

  token = strtok(buf, ",");
  while (token != NULL && idx < 5) {
    values[idx++] = atoi(token);
    token = strtok(NULL, ",");
  }

  if (idx == 5) {
    l90 = values[0];
    l45 = values[1];
    r45 = values[2];
    r90 = values[3];
    laps = values[4];
  }
}

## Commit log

2025-09-17 Rename Team-Photos/Imagen de WhatsApp 2025-09-17 a las 16.57.53_1d74a822.jpg to Eric Guerrero photo.jpg
2025-10-16 Change image dimensions in README
    Updated image size for ultrasonic and PCB base.
2025-10-16 Revise sensor information and installation details
    Updated the README to reflect changes in sensor usage and installation.
2025-10-16 Enhance README with color calibration details
    Added detailed instructions for color calibration, including recommended steps, example LAB thresholds, and troubleshooting tips.
2025-10-16 Update README with color calibration example
    Added example values for color calibration in README.
2025-10-17 Enhance README with EV3 code and maneuver details
    Added detailed explanations for EV3 blocks code, parking maneuvers, recovery from crashes, and PID controller functionality.
